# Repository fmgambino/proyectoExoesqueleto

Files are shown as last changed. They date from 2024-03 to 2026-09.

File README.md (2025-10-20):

# Proyecto Exoesqueleto Pediátrico con Monitoreo Biométrico

Logo de Electronicagambino

Este proyecto tiene como objetivo desarrollar un exoesqueleto pediátrico para niños con Atrofia Muscular Espinal (AME), incorporando monitoreo biométrico mediante IoT. El exoesqueleto permitirá a los niños con AME pararse y caminar con la ayuda de un andador, brindándoles una mayor autonomía y calidad de vida.

## Descripción del Firmware

El firmware se desarrollará utilizando PlatformIO con el framework Arduino mediante Visual Studio Code. Se utilizará el microcontrolador ESP32-WROOM-32U para controlar los motores paso a paso, gestionar la comunicación IoT y monitorear la actividad muscular mediante el sensor ECG EMG AD8832.

## Componentes Principales

- Microcontrolador ESP32-WROOM-32U
- Motores Paso a Paso Nema 17
- Sensores Mioeléctricos para detección de movimiento
- Sensor ECG EMG AD8832 para monitoreo de actividad muscular
- Conexión WiFi y Bluetooth Low Energy (BLE) para comunicación IoT

## Configuración del Entorno de Desarrollo

1. Instala PlatformIO en Visual Studio Code.
2. Clona este repositorio en tu computadora.
3. Abre el proyecto en Visual Studio Code.
4. Configura el archivo `platformio.ini` con la información del ESP32.
5. Compila y carga el firmware en el ESP32.

## Estructura del Proyecto

- **/src**: Contiene el código fuente del firmware.
- **/docs**: Documentación adicional del proyecto.
- **/hardware**: Esquemáticos y diseño de hardware.

## Diagramas y Esquemáticos

### Diagrama de Ingeniería Simplificado
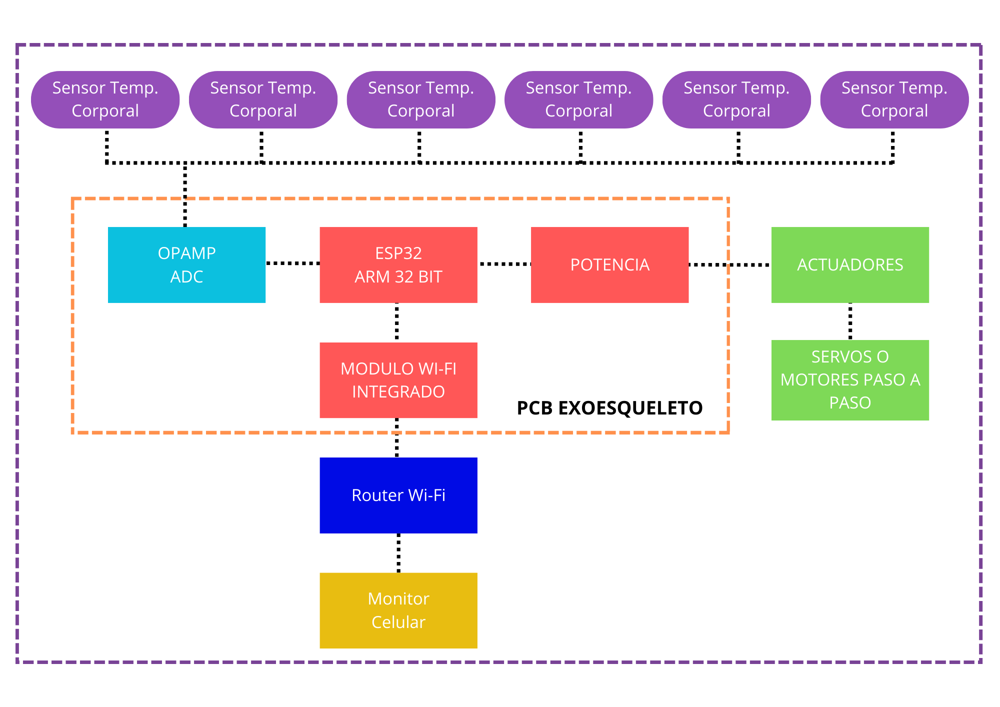
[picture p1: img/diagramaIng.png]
Diagrama de Ingeniería Simplificado


### Diagrama de Conectividad IoT mediante Broker EMQX
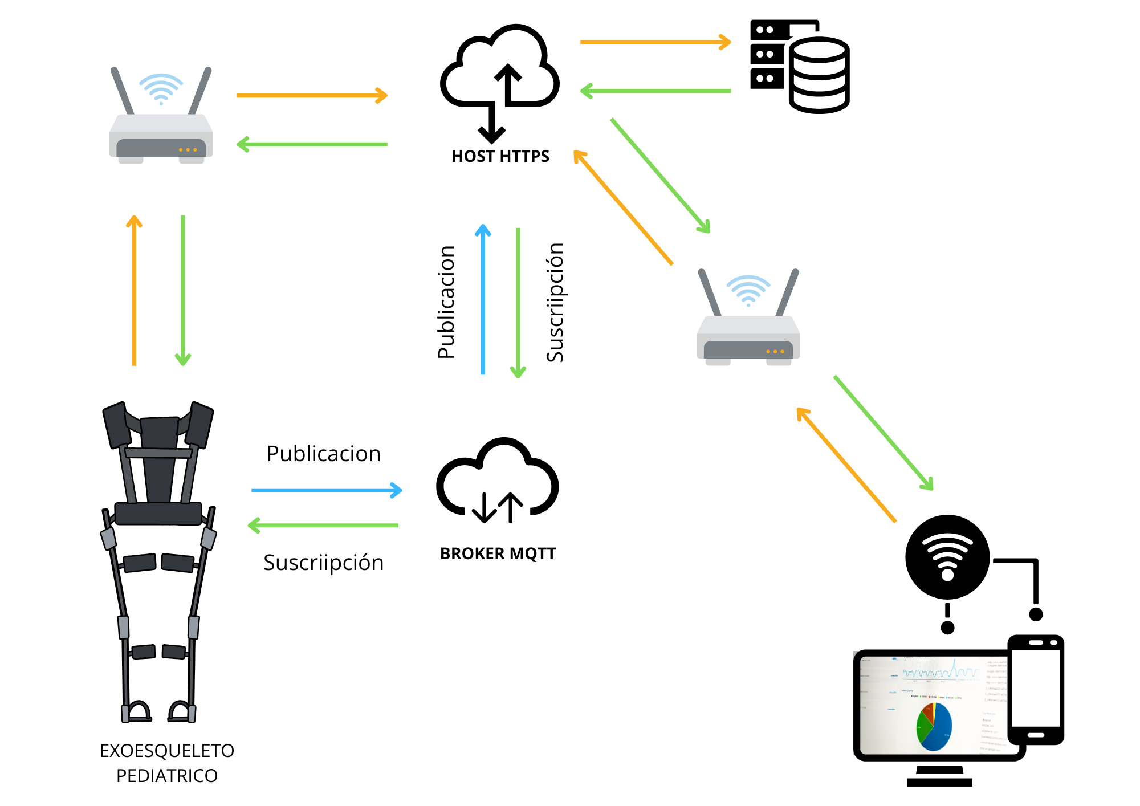
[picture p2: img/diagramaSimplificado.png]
Diagrama de Conectividad IoT


### Esquemático del Proyecto
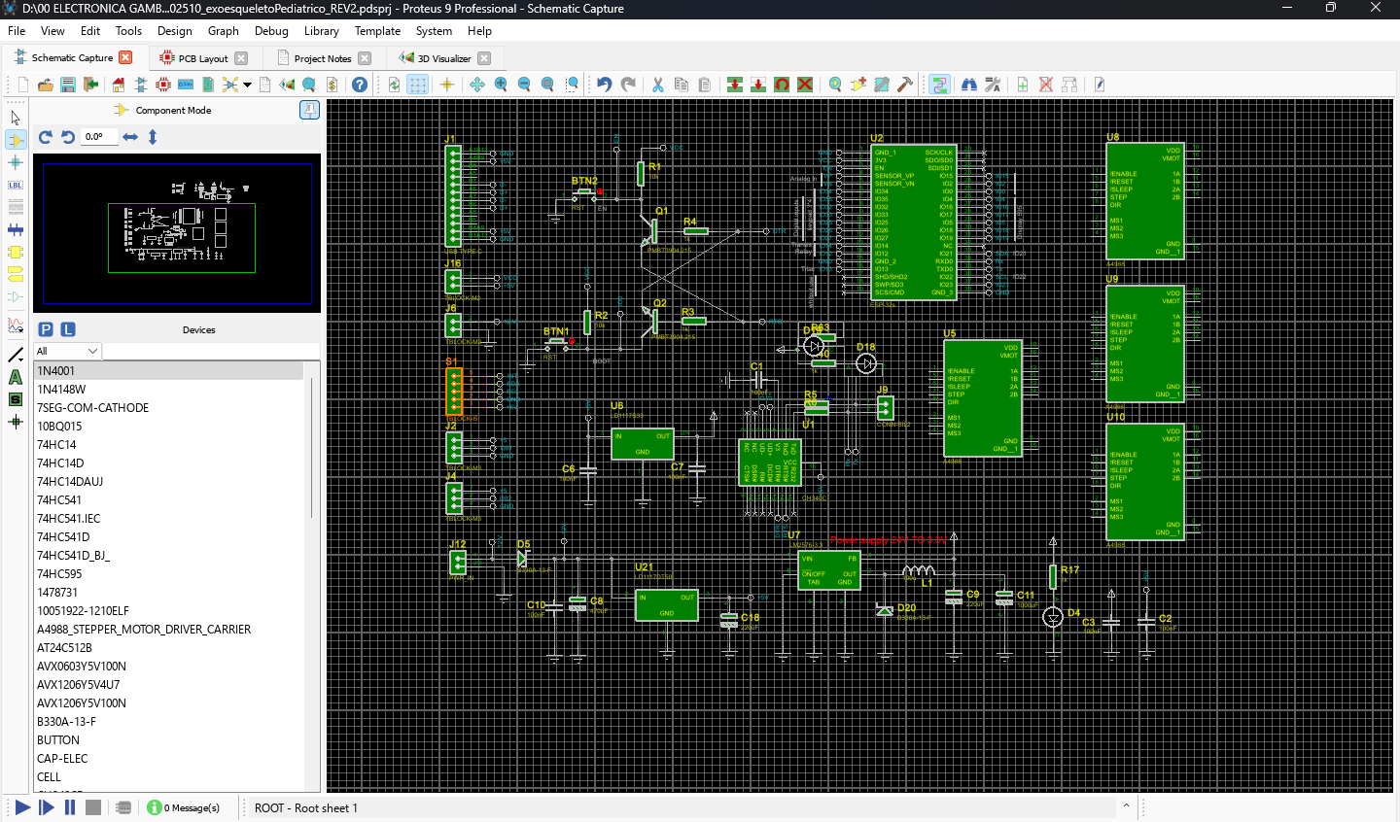
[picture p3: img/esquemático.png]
Esquemático


### Diseño  PCB LayOut´s del Proyecto
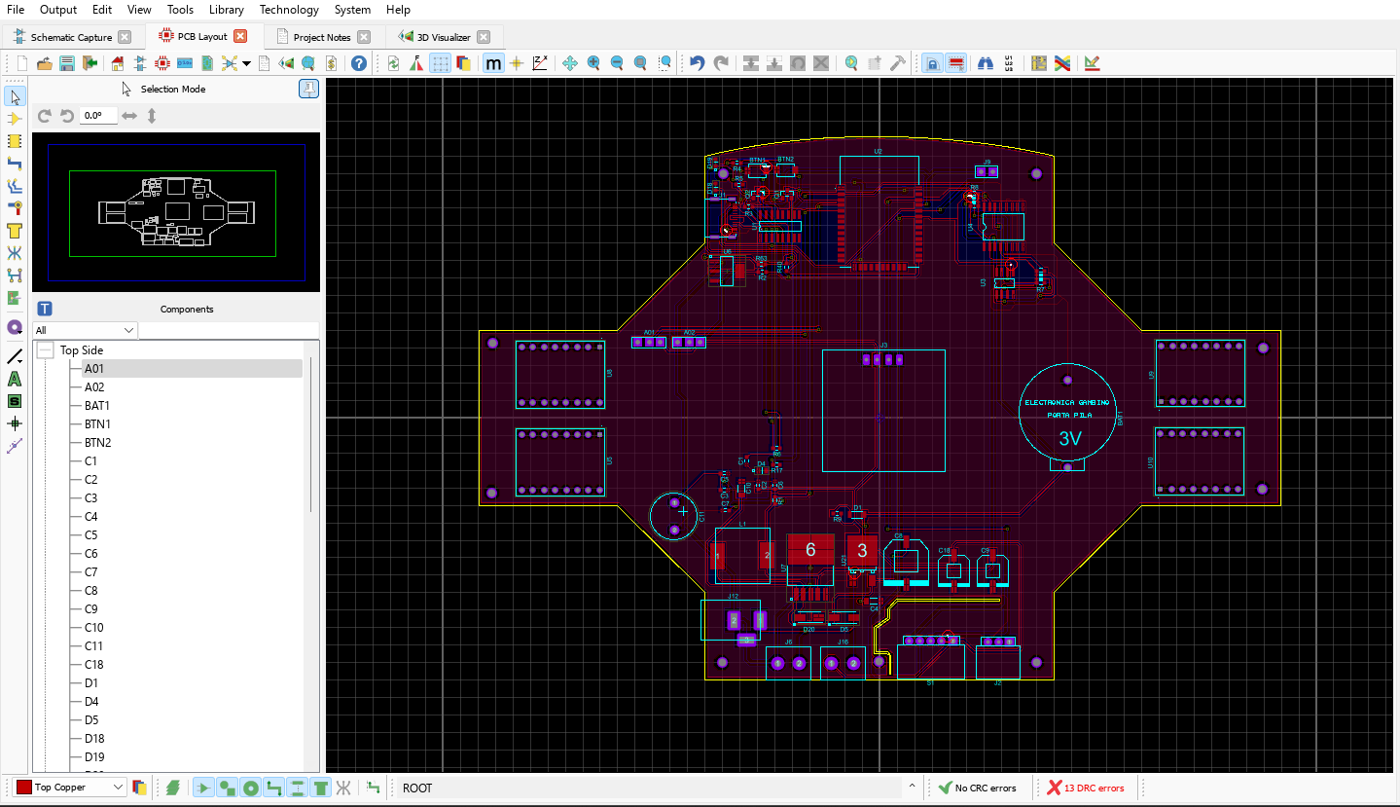
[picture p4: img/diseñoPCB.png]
PCB


### Modelado 3D PCB LayOut´s del Proyecto
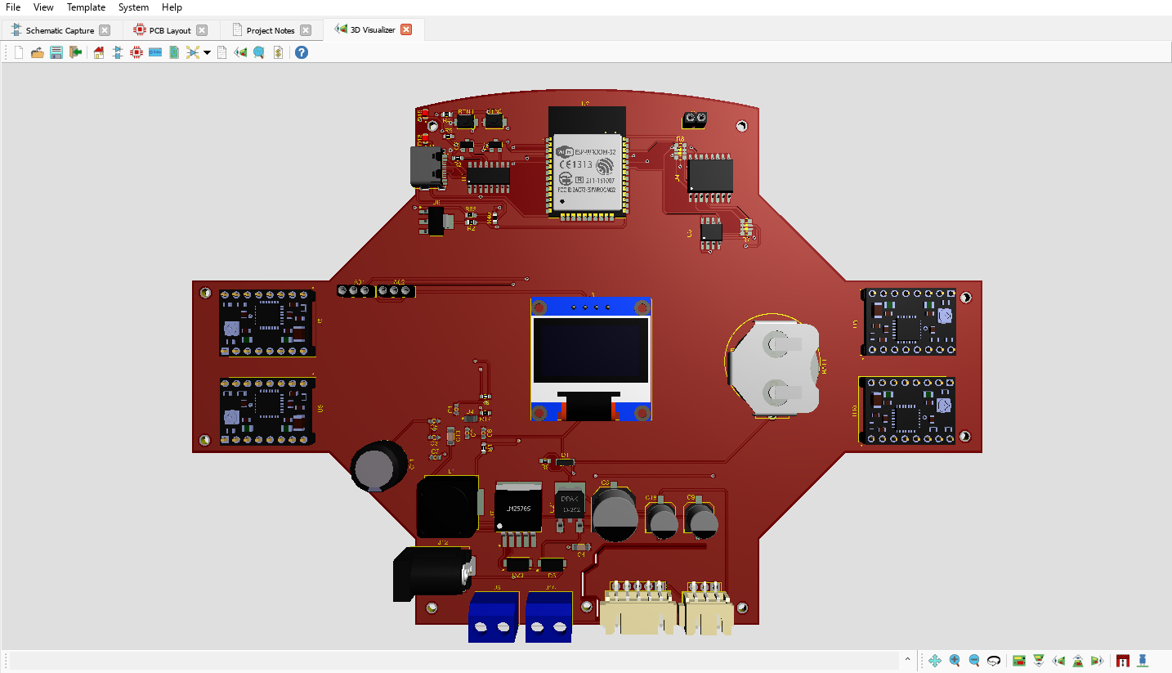
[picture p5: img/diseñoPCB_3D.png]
3D


## Uso del Firmware

El firmware controla los motores paso a paso en respuesta a las señales de los sensores mioeléctricos. Además, monitorea la actividad muscular utilizando el sensor ECG EMG AD8832. A continuación se describe cómo implementar y usar este sensor:

### Implementación del Sensor ECG EMG AD8832

1. Conecta el sensor ECG EMG AD8832 al pin analógico A0 del ESP32.
2. Proporciona la potencia adecuada al sensor según las especificaciones del fabricante.
3. Asegúrate de tener una buena conexión a tierra para reducir el ruido eléctrico.

### Detalles del Sensor

La medición de la actividad muscular se ha utilizado tradicionalmente en la investigación médica mediante la detección de la electromiografía (EMG). Sin embargo, con el advenimiento de microcontroladores más pequeños pero más potentes y circuitos integrados, los circuitos y sensores EMG se pueden utilizar en una variedad de aplicaciones de control de sistemas.

El sensor medirá la actividad eléctrica filtrada y rectificada de la salida muscular en un rango de 0 a Vs volts, donde la magnitud de la salida dependerá de la cantidad de actividad en el músculo seleccionado. Es fácil de usar con el controlador Arduino para detectar la actividad muscular.

### Forma de Uso del Sensor

El sensor ECG EMG AD8832 mide la actividad eléctrica de los músculos y proporciona una salida de voltaje proporcional a la actividad muscular. Puedes utilizar la siguiente función en tu código para medir esta actividad:

```cpp
#include <WiFi.h>
#include <BLEDevice.h>
#include <Stepper.h>

// Definición de pines para los motores paso a paso
#define MOTOR_1_STEP_PIN 2
#define MOTOR_1_DIR_PIN 3
#define MOTOR_2_STEP_PIN 4
#define MOTOR_2_DIR_PIN 5

// Definición de pines para el sensor muscular ECG EMG AD8832
#define EMG_SENSOR_PIN A0

// Definición de constantes para la configuración de los motores paso a paso
#define STEPS_PER_REVOLUTION 200
#define MOTOR_SPEED 200 // Velocidad en pasos por segundo

// Declaración de objetos Stepper para controlar los motores
Stepper stepperMotor1(STEPS_PER_REVOLUTION, MOTOR_1_STEP_PIN, MOTOR_1_DIR_PIN);
Stepper stepperMotor2(STEPS_PER_REVOLUTION, MOTOR_2_STEP_PIN, MOTOR_2_DIR_PIN);

// Variable para almacenar el estado del movimiento
bool isMoving = false;

// Función para inicializar la conexión WiFi
void setupWiFi() {
  // Coloca aquí tu código de inicialización de WiFi
}

// Función para inicializar la conexión BLE (Bluetooth Low Energy)
void setupBLE() {
  // Coloca aquí tu código de inicialización de BLE
}

// Función para inicializar el sensor muscular EMG
void setupEMGSensor() {
  pinMode(EMG_SENSOR_PIN, INPUT);
}

// Función para medir la actividad muscular con el sensor EMG
float measureMuscleActivity() {
  // Leer el valor del sensor EMG
  int emgValue = analogRead(EMG_SENSOR_PIN);

  // Convertir el valor a voltaje
  float voltage = emgValue * (3.3 / 4095.0); // 3.3V de referencia, 12 bits de resolución

  // Devolver el voltaje medido
  return voltage;
}

// Función para mover los motores paso a paso
void moveMotors() {
  // Coloca aquí tu código para controlar los motores según las señales de los sensores mioeléctricos
}

// Función de inicialización
void setup() {
  // Inicialización de los pines de dirección de los motores
  pinMode(MOTOR_1_DIR_PIN, OUTPUT);
  pinMode(MOTOR_2_DIR_PIN, OUTPUT);

  // Inicialización de la conexión WiFi
  setupWiFi();

  // Inicialización de la conexión BLE
  setupBLE();

  // Inicialización del sensor muscular EMG
  setupEMGSensor();
}

// Función principal de bucle
void loop() {
  // Coloca aquí tu código principal de control de bucle
  moveMotors();

  // Medir la actividad muscular con el sensor EMG
  float muscleActivity = measureMuscleActivity();

  // Imprimir el valor medido en el puerto serie
  Serial.print("Actividad Muscular: ");
  Serial.print(muscleActivity);
  Serial.println(" V");
  
  // Agrega un retraso para evitar lecturas demasiado rápidas
  delay(1000);
}
```
## Modelo 3D del Exoesqueleto Pediátrico

Aquí puedes ver el modelo 3D del exoesqueleto pediátrico desde diferentes ángulos:

### Frente
Modelo 3D Exoesqueleto Pediátrico Frontal

### Perfil
Modelo 3D Exoesqueleto Pediátrico Perfil

## Ubicación Recomendada de los Sensores EMG

Para maximizar la efectividad del exoesqueleto pediátrico, es crucial ubicar estratégicamente los sensores EMG en áreas específicas del cuerpo del niño o niña. Se recomienda colocar los sensores en los siguientes lugares:

1. **Músculos Cuádriceps y Femorales**: 💪 Estos músculos son fundamentales para el movimiento de las piernas y el equilibrio al estar de pie. Colocar los sensores en esta área permitirá detectar la intención de movimiento de las piernas y activar los motores del exoesqueleto en consecuencia.

2. **Músculos Tibiales Anteriores**: 🦵 Estos músculos están involucrados en la flexión dorsal del pie y son esenciales para mantener la estabilidad al caminar. Colocar sensores aquí ayudará a detectar los cambios en el equilibrio y ajustar el soporte proporcionado por el exoesqueleto.

3. **Músculos Glúteos**: 🍑 Los músculos glúteos son importantes para la estabilidad de la pelvis y el movimiento de las caderas. Colocar sensores en esta área puede ayudar a detectar la intención de movimiento de las caderas y mejorar la marcha del niño o niña.

4. **Zona Lumbar**: 🤸‍♀️ La zona lumbar es crucial para mantener la postura erguida y la estabilidad del tronco. Colocar sensores aquí permitirá monitorear la actividad muscular central y proporcionar soporte adecuado para la columna vertebral.

5. **Antebrazos y Bíceps**: 💪 Estos músculos son importantes para el equilibrio y la estabilidad al estar de pie. Colocar sensores en esta área puede ayudar a detectar los cambios en la postura de los brazos y ajustar el soporte proporcionado por el exoesqueleto.

## Consideraciones Adicionales para el Diseño del Hardware

Además de la ubicación de los sensores EMG, hay varias consideraciones adicionales que deben tenerse en cuenta en el diseño del hardware del exoesqueleto pediátrico:

- **Ergonomía**: 🪑 El diseño del exoesqueleto debe ser ergonómico y cómodo para el niño o niña, permitiendo un rango completo de movimiento y evitando puntos de presión incómodos.

- **Ajustabilidad**: 📏 Se debe permitir cierto grado de ajuste en el exoesqueleto para adaptarse al crecimiento del niño o niña y para permitir modificaciones según las necesidades individuales.

- **Seguridad**: ⚠️ El exoesqueleto debe ser seguro de usar, con mecanismos de seguridad para evitar lesiones y sensores de detección de fallos para garantizar un funcionamiento seguro.

- **Peso y Tamaño**: 📦 El exoesqueleto debe ser lo más liviano y compacto posible para facilitar el uso diario y minimizar la fatiga del usuario.

- **Facilidad de Uso**: 🎈 El exoesqueleto debe ser fácil de poner y quitar, con controles intuitivos y claros para el usuario y cuidador.

Considerar estas variables durante el diseño del hardware garantizará que el exoesqueleto pediátrico sea efectivo, seguro y cómodo para su uso continuo.

## 📚 Bibliografía y Referencias

- [Artículo científico sobre la ubicación de sensores EMG para exoesqueletos](https://www.ncbi.nlm.nih.gov/pmc/articles/PMC5378727/)
- [Investigación sobre diseño ergonómico de exoesqueletos](https://www.ncbi.nlm.nih.gov/pmc/articles/PMC5699460/)

# Tutorial: Control de Exoesqueleto con Sensores y PID 🤖📡

En este tutorial, aprenderás a utilizar un ESP32 junto con sensores de acelerómetro y giroscopio (MPU6050) para controlar un exoesqueleto, manteniéndolo en equilibrio mediante un controlador PID (Proporcional-Integral-Derivativo).

## Materiales necesarios 🛠️

- ESP32
- Sensor MPU6050 (acelerómetro y giroscopio)
- Motores Nema 17 (4 unidades)
- Driver A4988 (4 unidades)
- Placa de circuito impreso (PCB)
- Batería
- Cables de conexión
- Herramientas de soldadura

## Paso 1: Configuración del hardware 🚀

1. Conecta el ESP32 y el sensor MPU6050 según el esquema de conexión proporcionado en el archivo de configuración.

2. Conecta los motores Nema 17 al Driver A4988 y luego al ESP32, teniendo en cuenta la configuración de tu exoesqueleto.

## Paso 2: Configuración del entorno de desarrollo 💻

1. Instala el IDE de Arduino y el complemento PlatformIO para Visual Studio Code.

2. Crea un nuevo proyecto en PlatformIO y selecciona el framework Arduino y el ESP32 como placa de destino.

## Paso 3: Instalación de bibliotecas 📚

1. Instala las siguientes bibliotecas desde el administrador de bibliotecas de PlatformIO:
   - `Wire.h` (para la comunicación I2C)
   - `MPU6050.h` (para el sensor MPU6050)
   - `PID_v1.h` (para el controlador PID)

## Paso 4: Implementación del código 📝

Utiliza el siguiente código como base para tu proyecto. Asegúrate de personalizarlo según la configuración específica de tu exoesqueleto y ajustar los parámetros del controlador PID según sea necesario.

```cpp
#include <Arduino.h>
#include <Wire.h>
#include <MPU6050.h>
#include <PID_v1.h>

// Definir los pines de los motores
const int motorCintura1Pin1 = 2;
const int motorCintura1Pin2 = 3;
const int motorCintura2Pin1 = 4;
const int motorCintura2Pin2 = 5;
const int motorRodilla1Pin1 = 6;
const int motorRodilla1Pin2 = 7;
const int motorRodilla2Pin1 = 8;
const int motorRodilla2Pin2 = 9;

// Definir los pines de los sensores
MPU6050 mpu;

// Constantes para el equilibrio
const int anguloObjetivoCintura = 90; // Ángulo objetivo para la cintura
const int anguloObjetivoRodilla = 90; // Ángulo objetivo para las rodillas
const double Kp = 2.0; // Constante proporcional del PID
const double Ki = 5.0; // Constante integral del PID
const double Kd = 1.0; // Constante derivativa del PID

double inputCintura, outputCintura, setpointCintura;
double inputRodilla, outputRodilla, setpointRodilla;
PID pidCintura(&inputCintura, &outputCintura, &setpointCintura, Kp, Ki, Kd, DIRECT);
PID pidRodilla(&inputRodilla, &outputRodilla, &setpointRodilla, Kp, Ki, Kd, DIRECT);

void setup() {
  // Inicializar el puerto serie
  Serial.begin(9600);

  // Inicializar el sensor MPU6050
  Wire.begin();
  mpu.initialize();

  // Configurar los pines de los motores como salida
  pinMode(motorCintura1Pin1, OUTPUT);
  pinMode(motorCintura1Pin2, OUTPUT);
  pinMode(motorCintura2Pin1, OUTPUT);
  pinMode(motorCintura2Pin2, OUTPUT);
  pinMode(motorRodilla1Pin1, OUTPUT);
  pinMode(motorRodilla1Pin2, OUTPUT);
  pinMode(motorRodilla2Pin1, OUTPUT);
  pinMode(motorRodilla2Pin2, OUTPUT);
  
  // Configurar el PID
  pidCintura.SetMode(AUTOMATIC);
  pidRodilla.SetMode(AUTOMATIC);

  // Establecer los valores de setpoint
  setpointCintura = anguloObjetivoCintura;
  setpointRodilla = anguloObjetivoRodilla;
}

void loop() {
  // Leer los valores del sensor MPU6050
  int16_t ax, ay, az, gx, gy, gz;
  mpu.getMotion6(&ax, &ay, &az, &gx, &gy, &gz);
  
  // Calcular el ángulo de inclinación en la cintura y las rodillas
  double anguloCintura = atan2(-ay, -az) * 180.0 / M_PI;
  double anguloRodilla = atan2(-ax, -az) * 180.0 / M_PI;

  // Actualizar los valores de entrada del PID
  inputCintura = anguloCintura;
  inputRodilla = anguloRodilla;

  // Calcular la salida del PID
  pidCintura.Compute();
  pidRodilla.Compute();
  
  // Ajustar los motores según la salida del PID
  ajustarMotorCintura(outputCintura);
  ajustarMotorRodilla(outputRodilla);
}

void ajustarMotorCintura(double velocidad) {
  // Ajustar la velocidad y la dirección de los motores de la cintura
  // Implementar un algoritmo de control PID aquí
  // Este es un ejemplo simple donde se ajustan los motores de forma proporcional a la salida del PID
  if (velocidad > 0) {
    digitalWrite(motorCintura1Pin1, HIGH);
    digitalWrite(motorCintura1Pin2, LOW);
    digitalWrite(motorCintura2Pin1, HIGH);
    digitalWrite(motorCintura2Pin2, LOW);
  } else {
    digitalWrite(motorCintura1Pin1, LOW);
    digitalWrite(motorCintura1Pin2, HIGH);
    digitalWrite(motorCintura2Pin1, LOW);
    digitalWrite(motorCintura2Pin2, HIGH);
  }
}

void ajustarMotorRodilla(double velocidad) {
  // Ajustar la velocidad y la dirección de los motores de las rodillas
  // Implementar un algoritmo de control PID aquí
  // Este es un ejemplo simple donde se ajustan los motores de forma proporcional a la salida del PID
  if (velocidad > 0) {
    digitalWrite(motorRodilla1Pin1, HIGH);
    digitalWrite(motorRodilla1Pin2, LOW);
    digitalWrite(motorRodilla2Pin1, HIGH);
    digitalWrite(motorRodilla2Pin2, LOW);
  } else {
    digitalWrite(motorRodilla1Pin1, LOW);
    digitalWrite(motorRodilla1Pin2, HIGH);
    digitalWrite(motorRodilla2Pin1, LOW);
    digitalWrite(motorRodilla2Pin2, HIGH);
  }
}
```
## Paso 5: Compilación y carga del programa ⚙️

1. Compila el programa en PlatformIO y verifica que no haya errores.

2. Conecta el ESP32 a tu computadora y carga el programa compilado en el ESP32. Puedes hacerlo utilizando un cable USB.

## Paso 6: Pruebas y ajustes 🧪

1. Prueba el exoesqueleto en condiciones controladas, verificando su capacidad para mantener el equilibrio.

2. Ajusta los parámetros del controlador PID según sea necesario para mejorar el rendimiento del exoesqueleto.

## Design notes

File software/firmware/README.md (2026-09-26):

# BIOTRON EXO Pediátrico V7

Proyecto PlatformIO para ESP32 DevKit V1 + visor web 3D.

Correcciones V7:
- Error C++ de asignación `Joints` corregido con `assignJoints()`.
- Modelo 3D centrado y estado inicial sentado con rodillas a 90°.
- Señales DEMO ECG tipo AD8232 y EMG tipo burst muscular.
- Gráficas ECG/EMG con escalas y unidades: ECG 0-1200 mV, EMG 0-1000 mV, tiempo en segundos.
- Al deshabilitar ECG o EMG se oculta el bloque completo.
- Iconos SVG profesionales en variables biomédicas.
- OLED SH1106: logo, proyecto, autores y parámetros biomédicos.

## Uso
1. Abrir carpeta en VS Code + PlatformIO.
2. Borrar `.pio` si viene de versiones anteriores.
3. Compilar y subir firmware.
4. Subir filesystem: PlatformIO > Upload Filesystem Image.
5. Conectarse al AP `BIOTRON_EXO` / `12345678` y abrir la IP del ESP32.

IMPORTANTE: `ENABLE_MOTION` está en `false` por seguridad. Activarlo solo en banco, sin persona y con E-STOP.

## V8 - ECG simulado mejorado
- Señal ECG DEMO reescrita para parecerse al AD8232 mostrado en SignalScope: baseline cercano a 500, QRS angosto alto, P y T visibles, deriva basal y ruido fino.
- Escala gráfica ECG: eje X en segundos, eje Y 0-1000 mV relativos.
- El filtro ECG conserva el pico R para que la morfología no quede suavizada en exceso.

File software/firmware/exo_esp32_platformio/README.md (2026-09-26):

# Exoesqueleto Pediatrico ESP32 - PlatformIO

Proyecto base con ESP32 DevKit v1, Arduino Framework, 2 MPU6050, 4 motores NEMA17 mediante drivers STEP/DIR y telemetria WebSocket para modelo 3D en tiempo real.

## Comandos

```bash
pio run
pio run -t upload
pio run -t uploadfs
pio device monitor
```

Al iniciar, el ESP32 crea el AP `EXO_PEDIATRICO_ESP32` con clave `12345678`. Abrir `http://192.168.4.1`.

## Advertencia

Este codigo NO garantiza estabilidad ni seguridad humana. Para uso real hacen falta sensores adicionales, arnes, parada de emergencia cableada, topes fisicos, pruebas con carga dummy y revision biomecanica.

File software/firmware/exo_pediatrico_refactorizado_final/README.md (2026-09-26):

# Exoesqueleto pediátrico ESP32 + visor 3D

Proyecto PlatformIO para ESP32 DevKit v1 con Framework Arduino.

## Funciones
- Web local servida desde LittleFS.
- Visor 3D Three.js refactorizado con rotación X/Y/Z, OrbitControls y rueda de mouse configurable.
- Telemetría WebSocket en tiempo real.
- 2 MPU6050, 4 motores NEMA17, ECG, EMG, SpO2 MAX30102/MAX30105, temperatura corporal DS18B20, LM35 ambiente y temperatura CPU ESP32.

## Uso
1. Ajustar pines en `src/main.cpp`.
2. `pio run -t upload`
3. `pio run -t uploadfs`
4. Conectarse al WiFi `EXO-PEDIATRICO` clave `exo123456`.
5. Abrir `http://192.168.4.1`.

## Seguridad
Este firmware es base de laboratorio. No usar con un paciente sin arnés, paro de emergencia cableado, límites mecánicos, sensores de presión por pie, validación clínica y supervisión profesional.

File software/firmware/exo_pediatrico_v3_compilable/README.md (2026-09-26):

# EXO Pediátrico V3 - ESP32 DevKit V1

Corrección principal: `platformio.ini` actualizado para usar las librerías actuales de ESPAsyncWebServer:

```ini
esp32async/ESPAsyncWebServer
esp32async/AsyncTCP
```

El error anterior se debía a que `me-no-dev/ESP Async WebServer` / `me-no-dev/AsyncTCP` quedó obsoleto/movido en el registro de PlatformIO.

## Pasos recomendados después de reemplazar el proyecto

1. Cerrar VS Code.
2. Borrar la carpeta `.pio` del proyecto anterior.
3. Abrir esta carpeta nueva en VS Code.
4. Ejecutar `PlatformIO: Clean`.
5. Ejecutar `PlatformIO: Build`.
6. Para subir web a LittleFS: `PlatformIO: Upload Filesystem Image`.
7. Para subir firmware: `PlatformIO: Upload`.

## Modo web

La interfaz en `data/` conserva:
- selector DEMO / REAL,
- visor 3D,
- rotación X/Y/Z,
- scroll del mouse,
- telemetría biomédica y estado ESP32.

## Seguridad

`ENABLE_PHYSICAL_MOTION` está en `false` por defecto. No habilitar movimiento físico sin arnés, E-STOP físico, topes mecánicos, limit switches, sensores de presión en pies y validación en banco.

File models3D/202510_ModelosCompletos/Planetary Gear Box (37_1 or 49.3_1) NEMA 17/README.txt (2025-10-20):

Compound Planetary Gear Box (37:1 or 49.3:1) NEMA 17, No Hardware.  by Gear_Down_For_What on Thingiverse: https://www.thingiverse.com/thing:2054378

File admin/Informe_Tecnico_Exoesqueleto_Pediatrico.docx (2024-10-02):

# Informe Técnico: Evaluación de Servos para Exoesqueleto Pediátrico

## Introducción

Este informe técnico evalúa la factibilidad de usar cuatro servos RDS51150 para construir un exoesqueleto pediátrico para una niña de 150 cm de altura y 30 kg de peso. Se realizarán cálculos para determinar si estos servos pueden proporcionar el torque necesario para mover y sostener el peso de la niña.

## Datos del Servo y del Usuario

Datos del servo:
- Torque máximo: 150 kg·cm (14.715 N·m)
- Ángulo de control: 270°
- Voltaje: 12V

Datos del usuario:
- Altura de la niña: 150 cm
- Peso de la niña: 30 kg

## Consideraciones para el Exoesqueleto

1. Peso de la niña: 30 kg
2. Distribución del peso: Asumiremos que el exoesqueleto debe soportar el 50% del peso en cada pierna, es decir, 15 kg por pierna.
3. Distancia del punto de aplicación de la fuerza (longitud de la pierna): Aproximadamente la mitad de la altura de la niña, es decir, 75 cm.

## Cálculos

### Conversión del torque de los servos

El torque de los servos está dado en kg·cm, lo convertiremos a N·m para tener unidades consistentes.

1 kg·cm = 0.0981 N·m

Por lo tanto, 150 kg·cm = 150 * 0.0981 N·m = 14.715 N·m

### Fuerza necesaria por pierna

La fuerza necesaria para sostener 15 kg (parte del peso de la niña por pierna) es:

F = m * g = 15 kg * 9.81 m/s² = 147.15 N

### Momento de fuerza (Torque) necesario por pierna

El momento de fuerza (torque) necesario para levantar la pierna se calcula considerando la distancia desde el punto de rotación (asumiremos la cadera como punto de rotación):

τ = F * d = 147.15 N * 0.75 m = 110.3625 N·m

### Torque proporcionado por los servos

Cada pierna tendrá dos servos. Si se asume que el torque se distribuye uniformemente entre los dos servos por pierna, entonces el torque proporcionado por un servo será:

Torque proporcionado por servo = 14.715 N·m

## Evaluación de Factibilidad

Cada pierna necesita un torque de 110.3625 N·m, y cada pierna tendrá dos servos, por lo tanto, el torque total proporcionado por los dos servos será:

Torque total proporcionado por dos servos = 2 * 14.715 N·m = 29.43 N·m

Dado que 29.43 N·m es mucho menor que el torque necesario de 110.3625 N·m, los servos especificados no serán suficientes para mover y sostener el peso de la niña en un exoesqueleto.

## Conclusión

Los servos RDS51150 con un torque máximo de 150 kg·cm (14.715 N·m) no son adecuados para construir un exoesqueleto para una niña de 150 cm y 30 kg. Se requerirían servos con un torque significativamente mayor para soportar y mover el peso de la niña.

## Servos Adecuados

Para determinar qué servos serían adecuados, necesitamos calcular el torque mínimo necesario y buscar servos que cumplan o superen ese requisito. Hemos determinado que cada pierna requiere un torque de 110.3625 N·m para sostener la mitad del peso de la niña. Asumiremos que queremos usar dos servos por pierna, por lo que cada servo debe proporcionar la mitad de este torque.

Torque necesario por servo:
Torque necesario por servo = 55.18125 N·m

Conversión del torque a kg·cm:
Dado que 1 N·m = 10.1972 kg·cm,

Torque necesario por servo en kg·cm = 55.18125 N·m * 10.1972 kg·cm/N·m = 562.46 kg·cm

Por lo tanto, cada servo debe proporcionar al menos 562.46 kg·cm de torque.

Servos adecuados:
- Hitec HSR-5980SG: Torque máximo de aproximadamente 583 kg·cm (aproximadamente 57 N·m)
- Actuonix L16: Torque máximo varía según el modelo, pero algunos pueden alcanzar más de 562 kg·cm
- Dynamixel Pro+ H54-200-S500-R: Torque máximo de 44.7 N·m (es posible usar múltiples servos en configuraciones personalizadas para alcanzar el torque necesario)

En conclusión, se requieren servos con un torque mínimo de 562.46 kg·cm para garantizar la funcionalidad adecuada del exoesqueleto.

## Uso de Engranajes para Aumentar el Torque

Utilizar un mecanismo de engranajes puede multiplicar el torque proporcionado por los servos originales, haciéndolos potencialmente adecuados para el exoesqueleto.

Datos del servo original:
- Torque máximo: 150 kg·cm (14.715 N·m)

Torque necesario por pierna:
- Torque necesario: 110.3625 N·m
- Torque necesario por servo (si se usan dos por pierna): 55.18125 N·m

Ratio de engranaje necesario:
Ratio de engranaje = Torque necesario / Torque proporcionado
Ratio de engranaje = 55.18125 N·m / 14.715 N·m ≈ 3.75

Esto significa que necesitamos un sistema de engranajes con una relación de aproximadamente 3.75:1 para multiplicar el torque del servo original hasta alcanzar el torque requerido.

Consideraciones prácticas:
- Eficiencia: Los engranajes no son 100% eficientes. Debes considerar la pérdida de eficiencia, que puede ser alrededor del 90% o 0.9 para un buen sistema de engranajes.
- Espacio y peso: Los engranajes adicionales agregarán peso y ocuparán espacio, lo cual debe ser considerado en el diseño del exoesqueleto.

Ratio de engranaje ajustado con eficiencia:
Si asumimos una eficiencia del 90%:
Torque ajustado = Torque necesario / (Torque proporcionado * Eficiencia)
Ratio de engranaje ajustado = 55.18125 N·m / (14.715 N·m * 0.9) ≈ 4.17

En conclusión, se puede utilizar un sistema de engranajes con una relación de 4.17:1 para hacer que los servos originales sean adecuados para el exoesqueleto pediátrico.

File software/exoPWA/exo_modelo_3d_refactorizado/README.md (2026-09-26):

# Exoesqueleto Pediátrico 3D - Refactor

Abrir `index.html` con un servidor local, por ejemplo:

```bash
python -m http.server 8080
```

Luego entrar a `http://localhost:8080`.

Mejoras incluidas:
- OrbitControls sin bloqueo: giro completo, pan y zoom.
- Slider de rotación del modelo sobre eje Z.
- Diseño profesional tipo HUD.
- Animación GSAP estilo After Effects.
- WebSocket listo para ESP32: `ws://<host>:81/` con JSON `{lh,rh,lk,rk,rotZ}` en grados.

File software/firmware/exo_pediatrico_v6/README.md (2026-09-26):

# BIOTRON EXO Pediátrico V6

Proyecto PlatformIO para ESP32 DevKit v1 con visor 3D, telemetría biomédica, modo DEMO/REAL, OLED SH1106 y WebSocket.

## Correcciones V6
- Modelo 3D centrado y cámara corregida.
- Estado inicial sentado: rodillas a 90°.
- Logo BIOTRON en OLED como bitmap 128x64.
- Tarjetas biomédicas con iconos y unidades.
- Gráficas ECG y EMG en colores distintos, con ejes y unidades.
- Si se deshabilita ECG o EMG, la curva queda oculta.
- Demo simulada activa sin depender del ESP32.

## Uso
1. Abrir la carpeta en VS Code + PlatformIO.
2. Borrar `.pio` si existe.
3. Compilar: `PlatformIO: Build`.
4. Subir firmware: `PlatformIO: Upload`.
5. Subir web: `PlatformIO: Upload Filesystem Image`.
6. Conectarse al AP `BIOTRON_EXO`, contraseña `12345678`.

> Seguridad: `ENABLE_MOTION` está en `false`. Activarlo solo en banco de pruebas, sin persona.

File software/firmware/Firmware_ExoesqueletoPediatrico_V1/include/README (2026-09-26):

s” alimentada desde imágenes de reclamos.

## Cambiar imagen o video de fondo de la landing

### Imagen
Editá `styles.css`:

```css
.hero-section {
  --hero-image: linear-gradient(...), url('assets/hero-bg.svg');
}
```

Podés reemplazar `assets/hero-bg.svg` por `assets/hero-bg.jpg` o cualquier imagen propia.

### Video
En `index.html`, buscá:

```html
<!-- <video class="hero-video" autoplay muted loop playsinline src="assets/hero-bg.mp4"></video> -->
```

Quitá los comentarios y subí tu video como:

```text
assets/hero-bg.mp4
```

## Base de datos

No necesitás una columna nueva para URL de imagen: se guarda en `reports.image_urls` junto con las imágenes subidas. Ejecutá igualmente `database/database.sql` si venís de una versión anterior para asegurar columnas, políticas y Storage.

## v8 - Slider, landing y Cafecito

- El bloque **“Así se ven las calles”** ahora usa un slider interactivo con imágenes o video de los reclamos.
- Desde el **Panel Administrador > Slider de evidencia** podés cambiar efecto: `Slide`, `Fade` o `Zoom`, tiempo en milisegundos y autoplay.
- Se agregó sección **“Quién impulsa esta iniciativa”**.
- Se agregó botón **Cafecito** en header y footer.
- El popup del marcador muestra imagen principal 500x500px, antigüedad, fecha de reporte y estado con borde/color.

Para persistir la configuración del slider en Sup

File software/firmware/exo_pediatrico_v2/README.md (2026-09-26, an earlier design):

# EXO Pediátrico ESP32 + Visor 3D V2

Proyecto PlatformIO para ESP32 DevKit V1 con visor 3D, modo DEMO con datos simulados y modo REAL por WebSocket.

## Uso
1. Abrir con PlatformIO.
2. Compilar y subir firmware: `pio run -t upload`.
3. Subir web al LittleFS: `pio run -t uploadfs`.
4. Conectarse al WiFi `EXO-PEDIATRICO`, clave `exo123456`.
5. Abrir `http://192.168.4.1/`.

## Modo visualizador
- DEMO: no requiere ESP32; genera telemetría y movimientos simulados.
- REAL: conecta al WebSocket del ESP32 y muestra sensores/motores reales.

## Controles 3D
- Arrastrar mouse: orbitar.
- Rueda: zoom o rotación según selector.
- Shift + rueda: rotación Y.
- Alt + rueda: rotación X.
- Sliders X/Y/Z: rotación absoluta del modelo.

## Seguridad
Este firmware es una base de banco y visualización. No habilita movimiento físico por defecto. Para pruebas con persona se requieren sensores redundantes, topes mecánicos, E-STOP cableado, arnés y validación clínica/ingenieril.

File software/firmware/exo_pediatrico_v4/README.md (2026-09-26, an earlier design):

# EXO Pediátrico V4 - ESP32 DevKit V1 + visor 3D + ECG/EMG

Proyecto PlatformIO / Arduino para ESP32 DevKit V1.

## Cambios V4
- Estado inicial visual y lógico: **sentado a 90°**.
- Botón **Pararse + caminatas**: levanta desde sentado y ejecuta secuencia adelante, atrás, derecha e izquierda.
- Modelo 3D más parecido al prototipo: parte superior tipo carrito/trolley, placa negra, rieles laterales, rueditas, perfiles negros, carcazas grises, NEMA17 y pies pediátricos.
- Rotación X/Y/Z por sliders y rueda del mouse.
- Selector **DEMO / REAL**.
- Popup con gráficas ECG y EMG usando Chart.js CDN, con filtros independientes de visualización.
- Librerías PlatformIO corregidas: `esp32async/ESPAsyncWebServer` y `esp32async/AsyncTCP`.

## Uso
1. Abrir la carpeta en VS Code + PlatformIO.
2. Borrar `.pio` si viene de un proyecto anterior.
3. Compilar: `PlatformIO: Build`.
4. Subir firmware: `PlatformIO: Upload`.
5. Subir web: `PlatformIO: Upload Filesystem Image`.
6. Abrir la IP que muestra el monitor serial. Si no conecta WiFi, crea AP: `EXO-PEDIATRICO` clave `12345678`.

## Seguridad
`ENABLE_MOTION` está en `false` por defecto. Cambiar a `true` solo en banco de pruebas, sin persona, con E-STOP físico, arnés, topes mecánicos, sensores de presión en pies, encoders absolutos y supervisión.

Con 2 MPU6050 no se puede garantizar que no caiga. Para uso real se recomiendan: sensores FSR/celdas de carga por pie, encoders absolutos en articulaciones, finales de carrera, IMU adicional en torso, botón E-STOP cableado, medición de corriente de motores y arnés.

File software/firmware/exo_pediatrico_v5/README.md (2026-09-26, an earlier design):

# BIOTRON EXO Pediátrico V5

Correcciones incluidas:
- Visor 3D visible y más parecido al prototipo: trolley superior, perfiles negros, carcasas grises, NEMA17, cableado y pies pediátricos.
- Modo DEMO / REAL. DEMO muestra datos simulados aunque no haya ESP32 conectado.
- Secuencia inicial: sentado 90° → pararse → caminata adelante, atrás, derecha e izquierda.
- Popup con gráficas ECG y EMG usando Chart.js, con señal filtrada por separado.
- Firmware PlatformIO ESP32 DevKit v1 corregido sin `StaticJsonDocument`.
- OLED SH1106: logo/texto BIOTRON, pantalla de proyecto, autores y parámetros biomédicos.

## Uso
1. Abrir el proyecto en VS Code + PlatformIO.
2. Ejecutar `Build`.
3. Ejecutar `Upload Filesystem Image`.
4. Ejecutar `Upload`.
5. Conectarse al AP `BIOTRON_EXO`, password `12345678`, abrir `http://192.168.4.1/`.

## Seguridad
`ENABLE_MOTION` está en `false`. Cambiar a `true` solo en banco de pruebas, sin persona, con paro de emergencia físico, finales de carrera, arnés y supervisión.

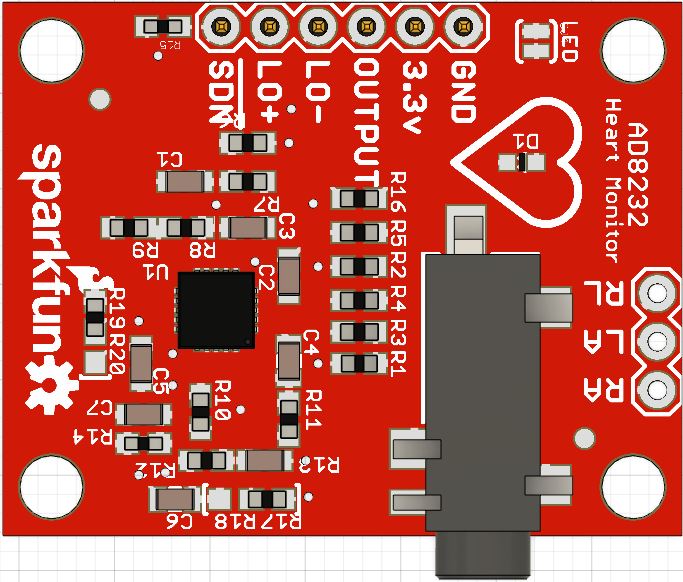
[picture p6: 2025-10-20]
hardware/mcad/ad8232-2.snapshot.2/AD83232.JPG

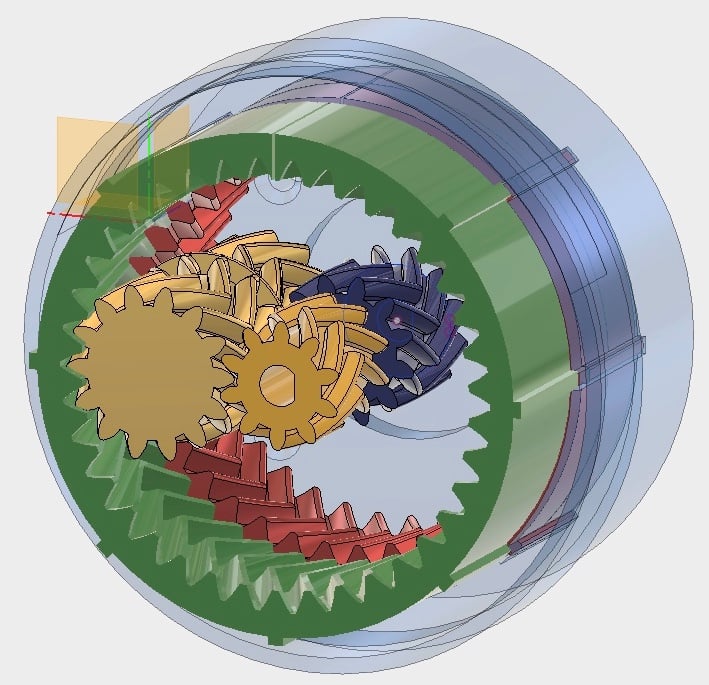
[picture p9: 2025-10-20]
models3D/202510_ModelosCompletos/Planetary Gear Box (37_1 or 49.3_1) NEMA 17/images/fullsizeoutput_700.jpeg

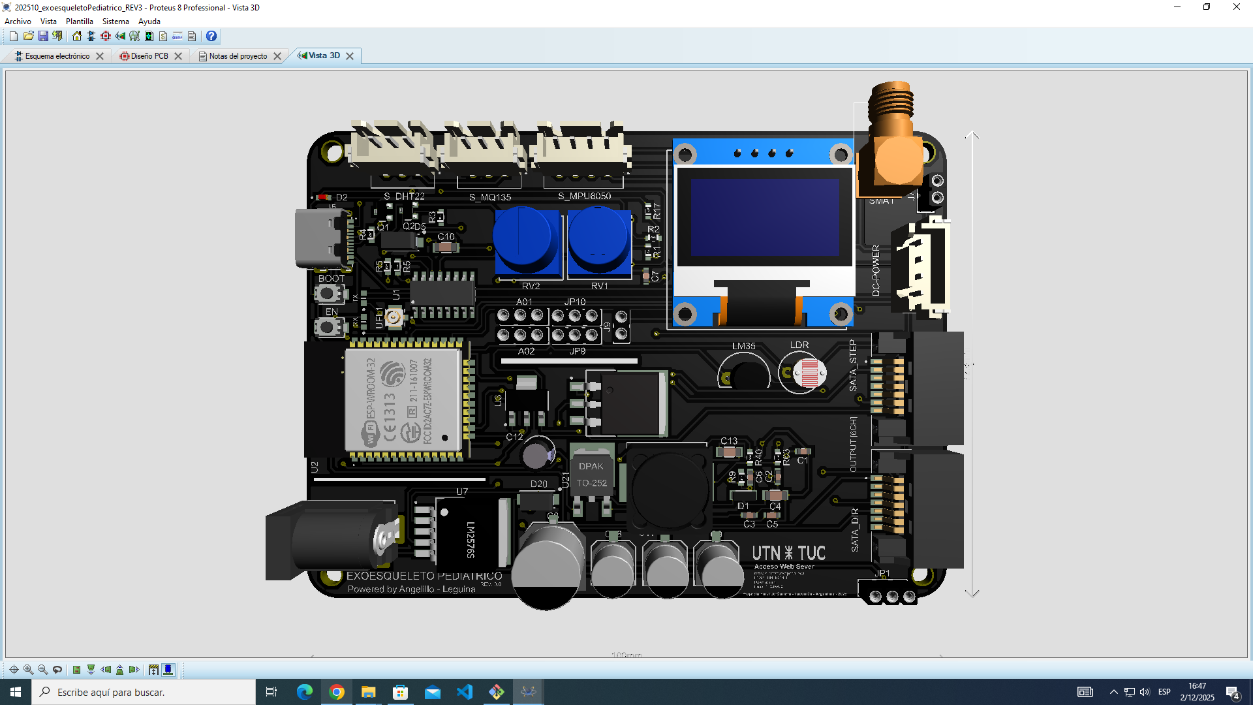
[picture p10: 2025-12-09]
img/pcbExo__control_frontal.png

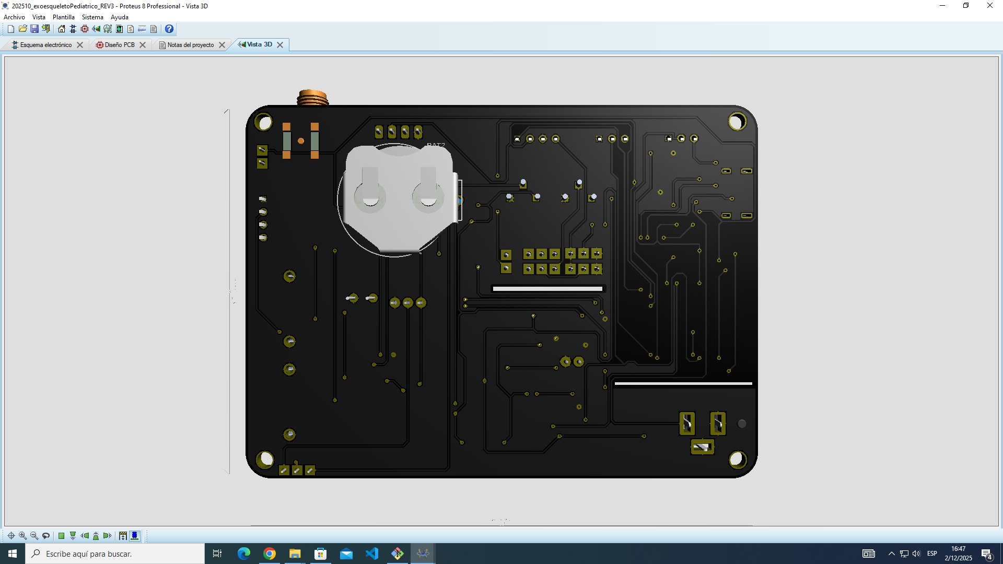
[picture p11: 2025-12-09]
img/pcbExo__control_reverso.png

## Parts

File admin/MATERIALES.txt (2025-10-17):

*MATERIALES* 

1 Rollo c/carretel
30 Tuercas m2
30 Tornillos Allen M5x10mm
3 Motores Nema 17
4 Drive A4988
2 Baterías CNHL Black Serie 6s 1100mAh 22.2V 
ó Fuente Switching Metálica 24v 10a

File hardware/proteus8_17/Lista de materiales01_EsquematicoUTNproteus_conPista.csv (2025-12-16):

Categoría | Referencias | Valor | Código almacén | Coste unitario
Condensadores | C1 | 47uF | C264234 | $0.03
Condensadores | C2 | 100nF | C77055 | $0.01
Condensadores | C3 | 470uF | C263985 | $0.11
Condensadores | C4 | 220uF | C294521 | $0.04
Condensadores | C5 | 100nF | C77055 | $0.01
Condensadores | C6 | 100nF | C77055 | $0.01
Condensadores | C7 | 100nF | C77055 | $0.01
Condensadores | C8 | 100nF | C77055 | $0.01
Condensadores | C9 | 100nF | C77055 | $0.01
Condensadores | C10 | 100nF | C77055 | $0.01
Condensadores | C11 | 100nF | C77055 | $0.01
Condensadores | C12 | 100nF | C77055 | $0.01
Condensadores | C13 | 220uF | C294521 | $0.04
Condensadores | C19 | 100nF | C77055 | $0.01
Condensadores | C22 | 100nF | C77055 | $0.01
Condensadores | C23 | 100nF | C77055 | $0.01
Condensadores | C24 | 100nF | C77055 | $0.01
Condensadores | C25 | 100nF | C77055 | $0.01
Condensadores | C34 | 10uF | C513774 | $0.06
Condensadores | C35 | 100nF | C77055 | $0.01
Resistencias | R1 | 680 | C103775 | $0.00
Resistencias | R2 | 680 | C103775 | $0.00
Resistencias | R3 | 680 | C103775 | $0.00
Resistencias | R4 | 680 | C103775 | $0.00
Resistencias | R5 | 10k | C73809 | $0.00
Resistencias | R6 | 10k | C73809 | $0.00
Resistencias | R7 | 10k | C73809 | $0.00
Resistencias | R8 | 10k | C73809 | $0.00
Resistencias | R9 | 10k | C73809 | $0.00
Resistencias | R10 | 10k | C73809 | $0.00
Resistencias | R11 | 10k | C73809 | $0.00
Resistencias | R12 | 10k | C73809 | $0.00
Resistencias | R13 | 1k | C328340 | $0.00
Resistencias | R14 | 4.7K
Resistencias | R15 | 4.7K
Resistencias | R16 | 4.7K
Resistencias | R17 | 20k | C305317 | $0.00
Resistencias | R18 | 20k | C305317 | $0.00
Resistencias | R19 | 20k | C305317 | $0.00
Resistencias | R20 | 20k | C305317 | $0.00
Resistencias | R21 | 680 | C103775 | $0.00
Resistencias | R22 | 680 | C103775 | $0.00
Resistencias | R23 | 680 | C103775 | $0.00
Resistencias | R24 | 680 | C103775 | $0.00
Resistencias | R25 | 4.7K
Resistencias | R26 | 4.7K
Resistencias | R27 | 4.7K
Resistencias | R28 | 10k | C73809 | $0.00
Resistencias | R29 | 10k | C73809 | $0.00
Resistencias | R30 | 1k | C328340 | $0.00
Resistencias | R31 | 1k | C328340 | $0.00
Resistencias | R33 | 1k | C328340 | $0.00
Resistencias | R34 | 1k | C328340 | $0.00
Resistencias | R35 | 4.7K
Resistencias | R36 | 4.7K
Resistencias | R51 | 10k | C17414 | $0.00
Resistencias | R52 | 1k | C25623 | $0.00
Resistencias | R53 | 220 | C103414 | $0.00
Resistencias | R54 | 10k | C17414 | $0.00
Resistencias | R55 | 10k | C17414 | $0.00
Resistencias | R56 | 1k | C25623 | $0.00
Resistencias | R57 | 220 | C103414 | $0.00
Resistencias | R58 | 10k | C17414 | $0.00
Resistencias | R59 | 10k | C17414 | $0.00
Resistencias | R60 | 1k | C25623 | $0.00
Resistencias | R61 | 220 | C103414 | $0.00
Resistencias | R62 | 10k | C17414 | $0.00
Resistencias | R63 | 10k | C17414 | $0.00
Resistencias | R64 | 1k | C25623 | $0.00
Resistencias | R65 | 220 | C103414 | $0.00
Resistencias | R66 | 10k | C17414 | $0.00
Resistencias | R71 | 10k | C73809 | $0.00
Resistencias | R72 | 10k | C73809 | $0.00
Resistencias | R73 | 10k | C73809 | $0.00
Resistencias | R74 | 10k | C73809 | $0.00
Resistencias | R84 | 470 | C328361 | $0.00
Integrados | U1 | 74HC14 | C6821 | $0.12
Integrados | U2 | PC817XI1J
Integrados | U4 | PC817XI1J
Integrados | U5 | PC817XI1J
Integrados | U6 | PC817XI1J
Integrados | U7 | PC817XI1J
Integrados | U8 | DS3231SN
Integrados | U9 | TS78M05CP
Integrados | U10 | ESP-32s | C473012 | $3.19
Integrados | U11 | LM2576-3,3 | C194472 | $0.41
Integrados | U12 | LD1117S33 | C369933 | $0.07
Integrados | U13 | CH340C | C84681 | $0.39
Integrados | U14 | PC817XI1J
Integrados | U15 | PC817XI1J
Integrados | U16 | PC817XI1J
Integrados | U17 | ULN7812 TO263
Integrados | U18 | AT24C512B | C81193 | $0.18
Transistores | Q1 | PMBT3904,215 | C8667 | $0.01
Transistores | Q2 | PMBT3904,215 | C8667 | $0.01
Transistores | Q7 | FQD11P06TM | C719783 | $0.40
Transistores | Q8 | FQD11P06TM | C719783 | $0.40
Transistores | Q9 | FQD11P06TM | C719783 | $0.40
Transistores | Q10 | FQD11P06TM | C719783 | $0.40
Diodos | D00 | LED smd 0603 | C131269 | $0.03
Diodos | D01 | LED smd 0603 | C131269 | $0.03
Diodos | D02 | LED smd 0603 | C131269 | $0.03
Diodos | D03 | LED smd 0603 | C131269 | $0.03
Diodos | D9 | LED smd 0603 | C131269 | $0.03
Diodos | D10 | LED smd 0603 | C131269 | $0.03
Diodos | D11 | LED smd 0603 | C131269 | $0.03
Diodos | D12 | LED smd 0603 | C131269 | $0.03
Diodos | D28 | SS14-TP | C78082 | $0.05
Diodos | D29 | B330A-13-F | C110485 | $0.11
Diodos | D66 | 1N4148W | C511885 | $0.02
Miscelánea | BAT1 | 3V | C70376 | $0.06
Miscelánea | BTN1 | RST | C561519 | $0.06
Miscelánea | BTN2 | RST | C561519 | $0.06
Miscelánea | F1 | 1A | C3130 | $0.02
Miscelánea | FUENTE | TBLOCK-M2BLK |  | $0.40
Miscelánea | J1 | USB TYPE C | C309349 | $0.50
Miscelánea | J2 | HLK-10M12
Miscelánea | J3 | TBLOCK-M4
Miscelánea | J4 | TBLOCK-M4
Miscelánea | J6 | TBLOCK-M4
Miscelánea | J7 | TBLOCK-M2 |  | $0.40
Miscelánea | J8 | TBLOCK-M3
Miscelánea | L1 | 100u | C408533 | $0.55
Miscelánea | LCD | CONN-H4
Miscelánea | PW | LED-RED | C375458 | $0.02
Miscelánea | SPI | CONN-SIL6
Miscelánea | WI FI

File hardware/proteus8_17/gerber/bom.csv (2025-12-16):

Categoría | Referencias | Valor | Código almacén | Coste unitario
Condensadores | C1 | 100nF | C92490 | $0.00
Condensadores | C2 | 100nF | C92490 | $0.00
Condensadores | C3 | 100nF | C92490 | $0.00
Condensadores | C4 | 10uF | C513774 | $0.06
Condensadores | C5 | 100nF | C92490 | $0.00
Condensadores | C6 | 100nF | C92490 | $0.00
Condensadores | C7 | 100nF | C92490 | $0.00
Condensadores | C8 | 470uF | C263985 | $0.11
Condensadores | C9 | 220uF | C294521 | $0.04
Condensadores | C10 | 100nF | C309030 | $0.01
Condensadores | C11 | 1000uF | C503217 | $0.07
Condensadores | C12 | 220uF
Condensadores | C13 | 100nF | C309030 | $0.01
Condensadores | C18 | 220uF | C294521 | $0.04
Resistencias | R1 | 10k | C73809 | $0.00
Resistencias | R2 | 10k | C73809 | $0.00
Resistencias | R3 | 1k | C328340 | $0.00
Resistencias | R4 | 1k | C328340 | $0.00
Resistencias | R5 | 1k | C328340 | $0.00
Resistencias | R6 | 1k | C328340 | $0.00
Resistencias | R9 | 470 | C328361 | $0.00
Resistencias | R17 | 1k | C328340 | $0.00
Resistencias | R40 | 1k | C328340 | $0.00
Resistencias | R63 | 1k | C328340 | $0.00
Integrados | U1 | CH340C | C84681 | $0.39
Integrados | U2 | ESP-32s | C473012 | $3.19
Integrados | U3 | LM7812S
Integrados | U6 | LD1117S33 | C917183 | $0.13
Integrados | U7 | LM2576-3,3 | C347412 | $0.72
Integrados | U21 | LD1117DT50
Transistores | Q1 | PMBT3904,215 | C8667 | $0.01
Transistores | Q2 | PMBT3904,215 | C8667 | $0.01
Diodos | D1 | 1N4148W | C511885 | $0.02
Diodos | D2 | SMLD12U1WT86
Diodos | D5 | B330A-13-F | C110485 | $0.11
Diodos | D18 | LED-GREEN | C131269 | $0.03
Diodos | D19 | LED-GREEN | C131269 | $0.03
Diodos | D20 | B330A-13-F | C110485 | $0.11
Miscelánea | A01 | CONN-SIL3
Miscelánea | A02 | CONN-SIL3
Miscelánea | BAT2 | 3V | C70376 | $0.06
Miscelánea | BOOT | RST | C561523 | $0.06
Miscelánea | DC-POWER | B4BXHA
Miscelánea | EN | RST | C561523 | $0.06
Miscelánea | J1 | PWR_IN | Jack power
Miscelánea | J3 | OLED 128X64 | C30621 | $5.90
Miscelánea | J5 | USB TYPE C | C309349 | $0.50
Miscelánea | J7 | CONN-SIL2 | C492401 | $0.01
Miscelánea | J9 | CONN-SIL2 | C492401 | $0.01
Miscelánea | JP1 | JUMPER2
Miscelánea | JP9 | JUMPER2
Miscelánea | JP10 | JUMPER2
Miscelánea | L1 | 100u | C408533 | $0.55
Miscelánea | LDR | TORCH_LDR
Miscelánea | LM35 | LM35
Miscelánea | RV1 | 1k | C330455 | $0.43
Miscelánea | RV2 | 1k | C330455 | $0.43
Miscelánea | SATA_DIR | SATA_DATA
Miscelánea | SATA_STEP | SATA_DATA
Miscelánea | SMA1 | SMACONN
Miscelánea | S_ECG | CONNX3_MINI
Miscelánea | S_EMG | CONNX3_MINI
Miscelánea | S_MPU6050 | B4BXHA
Miscelánea | S_SPO2 | B4BXHA
Miscelánea | UFL1 | PIN UFL SMD

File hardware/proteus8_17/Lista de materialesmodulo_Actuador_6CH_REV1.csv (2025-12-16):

Categoría | Referencias | Valor | Código almacén | Coste unitario
Integrados | U1 | A4988
Integrados | U2 | A4988
Integrados | U3 | A4988
Integrados | U4 | A4988
Integrados | U5 | A4988
Integrados | U6 | A4988
Miscelánea | DC-POWER | B4BXHA
Miscelánea | J1 | TBLOCK-I4
Miscelánea | J2 | TBLOCK-I4
Miscelánea | J3 | TBLOCK-I4
Miscelánea | J4 | TBLOCK-I4
Miscelánea | J5 | TBLOCK-I4
Miscelánea | J6 | TBLOCK-I4
Miscelánea | SATA_DIR | SATA_DATA
Miscelánea | SATA_STEP | SATA_DATA

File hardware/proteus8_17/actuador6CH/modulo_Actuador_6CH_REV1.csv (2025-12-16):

Part ID | Value | Package | Stock Code | Layer | Rotation | X | Y
U1 | A4988 | A4988_MODULE_STEPPER_MOTOR_DRIVER_CARRIE |  | TOP | 0 | 775.984 | -1116.14
U2 | A4988 | A4988_MODULE_STEPPER_MOTOR_DRIVER_CARRIE |  | TOP | 0 | 775.984 | -1848.43
U3 | A4988 | A4988_MODULE_STEPPER_MOTOR_DRIVER_CARRIE |  | TOP | 0 | 1630.31 | -1116.14
U4 | A4988 | A4988_MODULE_STEPPER_MOTOR_DRIVER_CARRIE |  | TOP | 0 | 1618.5 | -1852.36
SATA_DIR | SATA_DATA | SATA_DATA |  | TOP | 90 | 1183.86 | -425.098
SATA_STEP | SATA_DATA | SATA_DATA |  | TOP | 90 | 2114.57 | -422.736
J1 | TBLOCK-I4 | CONN-SIL4 |  | TOP | 0 | 901.969 | -2299.21
J2 | TBLOCK-I4 | CONN-SIL4 |  | TOP | 0 | 1542.91 | -2303.15
J3 | TBLOCK-I4 | CONN-SIL4 |  | TOP | 0 | 2172.83 | -2307.09
J4 | TBLOCK-I4 | CONN-SIL4 |  | TOP | 0 | 906.693 | -2586.61
DC-POWER | B4BXHA | CONN-SIL4 |  | TOP | -90 | 236.22 | -1368.9
J5 | TBLOCK-I4 | CONN-SIL4 |  | TOP | 0 | 1543.7 | -2586.61
J6 | TBLOCK-I4 | CONN-SIL4 |  | TOP | 0 | 2173.62 | -2582.68
U5 | A4988 | A4988_MODULE_STEPPER_MOTOR_DRIVER_CARRIE |  | TOP | 0 | 2500.39 | -1116.14
U6 | A4988 | A4988_MODULE_STEPPER_MOTOR_DRIVER_CARRIE |  | TOP | 0 | 2500.39 | -1852.36

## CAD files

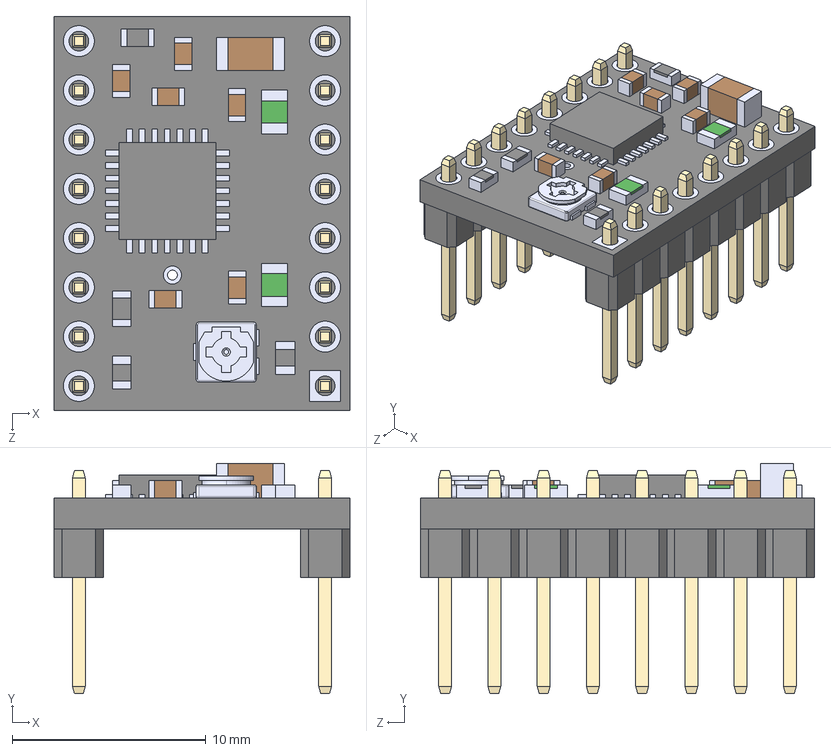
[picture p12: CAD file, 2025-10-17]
hardware/footprints/A4988_STEPPER_MOTOR_DRIVER_CARRIER/A4988_STEPPER_MOTOR_DRIVER_CARRIER.step
15.2 x 11.9 x 20.3 mm

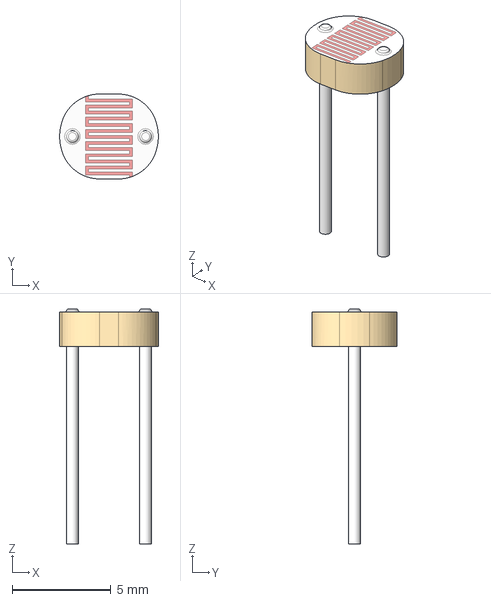
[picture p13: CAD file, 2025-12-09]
hardware/mcad/LDR v1.step
4.99 x 4.30 x 11.9 mm

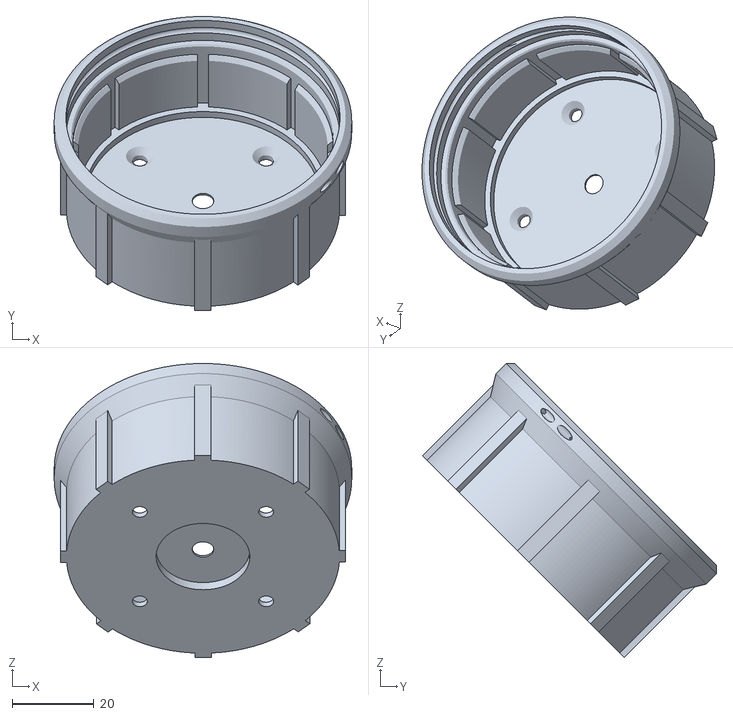
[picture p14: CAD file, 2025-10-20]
models3D/202510_ModelosCompletos/Planetary Gear Box (37_1 or 49.3_1) NEMA 17/files/Nema17_Mount_Update3_.stl
73.0 x 72.1 x 72.1

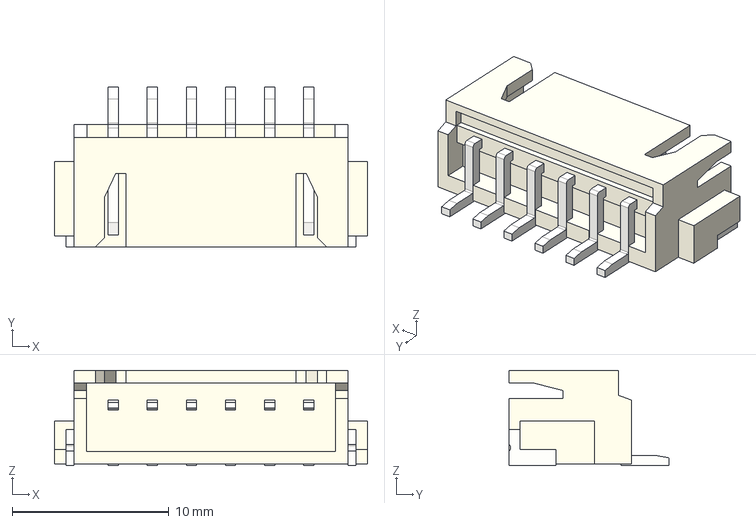
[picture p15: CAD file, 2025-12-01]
hardware/mcad/JST-XH6-SMD.step
20.0 x 10.2 x 6.10 mm

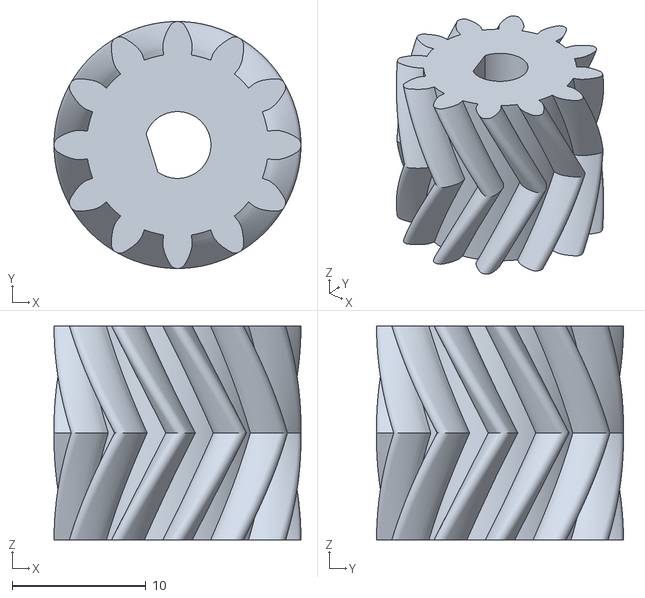
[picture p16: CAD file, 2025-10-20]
models3D/202510_ModelosCompletos/Planetary Gear Box (37_1 or 49.3_1) NEMA 17/files/Drive_Sun_37-1_.stl
18.5 x 18.5 x 16.0

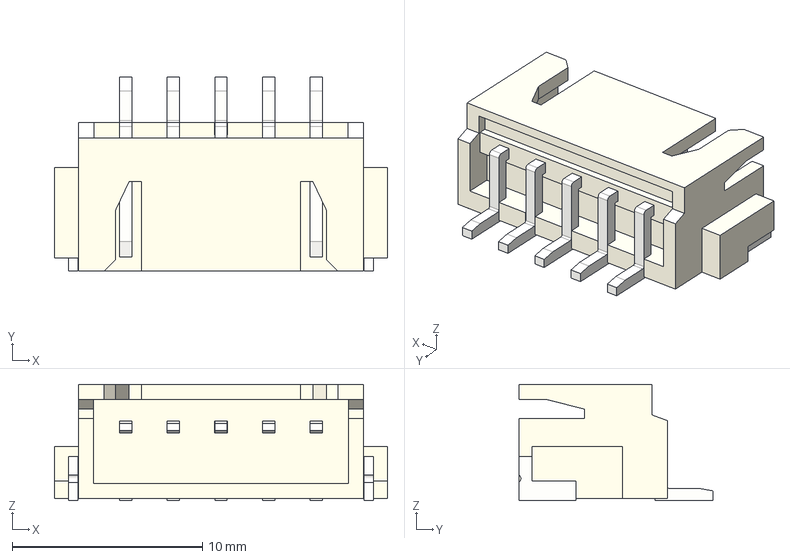
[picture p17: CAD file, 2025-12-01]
hardware/mcad/JST-XH5-SMD.step
17.5 x 10.2 x 6.10 mm

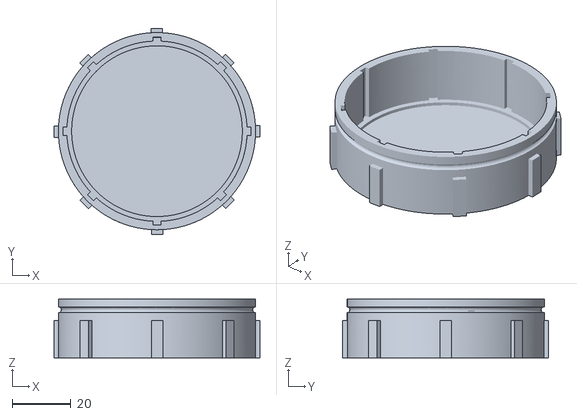
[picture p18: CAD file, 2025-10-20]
models3D/202510_ModelosCompletos/Planetary Gear Box (37_1 or 49.3_1) NEMA 17/files/End_Cap_Update_.stl
70.0 x 70.0 x 20.0

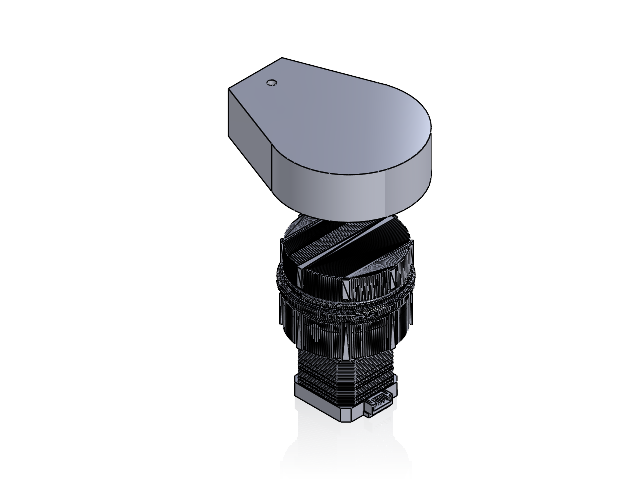
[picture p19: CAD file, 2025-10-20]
models3D/202510_ModelosCompletos/exoEsqueleto_3Ds_Models/Ensamblaje1.SLDASM
Stepper
Nema17_Mount_Update3_
End_Cap_Update_
ARTICULACION CHICA v2

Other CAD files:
models3D/nema-17-robot-arm-remix20231125-35007-alffvt/BookedDolphin/nema-17-robot-arm-remix/Arm_full_Assembly.SLDASM
models3D/202510_ModelosCompletos/exoEsqueleto_3Ds_Models/ENSAMBLE DE PIES.SLDASM
models3D/202510_ModelosCompletos/exoEsqueleto_3Ds_Models/Nema17_Mount_Update3_.SLDPRT
models3D/nema-17-robot-arm-remix20231125-35007-alffvt/BookedDolphin/nema-17-robot-arm-remix/Claw_jaw_copy.SLDPRT
models3D/Soporte Nema17 by EG.stl
models3D/202510_ModelosCompletos/exoEsqueleto_3Ds_Models/separadores.SLDPRT
models3D/Brazo Palanca & Soporte Nema17 by EG.stl
models3D/nema-17-robot-arm-remix20231125-35007-alffvt/BookedDolphin/nema-17-robot-arm-remix/Driven_gear_copy.SLDPRT
models3D/202510_ModelosCompletos/exoEsqueleto_3Ds_Models/tobillo.SLDPRT
models3D/nema-17-robot-arm-remix20231125-35007-alffvt/BookedDolphin/nema-17-robot-arm-remix/Claw_mount_copy.SLDPRT
hardware/mcad/AD8232 v4.step
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

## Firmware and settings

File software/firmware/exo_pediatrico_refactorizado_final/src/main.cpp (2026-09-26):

#include <Arduino.h>
#include <Wire.h>
#include <WiFi.h>
#include <LittleFS.h>
#include <ESPAsyncWebServer.h>
#include <ArduinoJson.h>
#include <Adafruit_MPU6050.h>
#include <Adafruit_Sensor.h>
#include <AccelStepper.h>
#include <OneWire.h>
#include <DallasTemperature.h>
#include <MAX30105.h>
#include "spo2_algorithm.h"

// ================== CONFIGURACION GENERAL ==================
#define ENABLE_MOTION false       // Cambiar a true solo en banco de pruebas, sin persona.
#define SERIAL_BAUD 115200
#define WS_RATE_MS 50
#define CONTROL_RATE_MS 10
#define SAFE_TILT_DEG 12.0f
#define MAX_JOINT_DEG 95.0f
#define MIN_JOINT_DEG -15.0f
#define STEP_ANGLE_DEG 1.2f       // NEMA17 1.2 grados/paso; ajustar microstepping abajo.
#define MICROSTEPS 16
#define STEPS_PER_DEG (MICROSTEPS / STEP_ANGLE_DEG)

// WiFi AP
const char* AP_SSID = "EXO-PEDIATRICO";
const char* AP_PASS = "exo123456";

// I2C
constexpr uint8_t I2C_SDA = 21;
constexpr uint8_t I2C_SCL = 22;
constexpr uint8_t MPU_LEFT_ADDR  = 0x68;
constexpr uint8_t MPU_RIGHT_ADDR = 0x69; // AD0 a 3V3 en el segundo MPU6050

// Pines analogicos biomedicos
constexpr uint8_t PIN_ECG = 34;
constexpr uint8_t PIN_EMG = 35;
constexpr uint8_t PIN_LM35 = 32;
constexpr uint8_t PIN_ESTOP = 27;  // NC recomendado: LOW = emergencia
constexpr uint8_t PIN_DS18B20 = 4;

// Drivers STEP/DIR para 4 NEMA17: LH, LK, RH, RK
constexpr uint8_t PIN_LH_STEP = 14, PIN_LH_DIR = 12;
constexpr uint8_t PIN_LK_STEP = 26, PIN_LK_DIR = 25;
constexpr uint8_t PIN_RH_STEP = 33, PIN_RH_DIR = 13;
constexpr uint8_t PIN_RK_STEP = 18, PIN_RK_DIR = 19;

AsyncWebServer server(80);
AsyncWebSocket ws("/ws");
Adafruit_MPU6050 mpuLeft, mpuRight;
OneWire oneWire(PIN_DS18B20);
DallasTemperature bodyTempSensor(&oneWire);
MAX30105 spo2Sensor;

AccelStepper mLH(AccelStepper::DRIVER, PIN_LH_STEP, PIN_LH_DIR);
AccelStepper mLK(AccelStepper::DRIVER, PIN_LK_STEP, PIN_LK_DIR);
AccelStepper mRH(AccelStepper::DRIVER, PIN_RH_STEP, PIN_RH_DIR);
AccelStepper mRK(AccelStepper::DRIVER, PIN_RK_STEP, PIN_RK_DIR);

struct ImuData { float ax=0, ay=0, az=0, gx=0, gy=0, gz=0, pitch=0, roll=0; bool ok=false; } imuL, imuR;
struct BioData { int ecg=0, emg=0; float spo2=0, bpm=0, bodyC=0, ambientC=0, cpuC=0; bool spo2Ok=false; } bio;
struct JointTargets { float lh=0, lk=0, rh=0, rk=0; } target, measured;

enum ExoMode { IDLE, SIT_TO_STAND, WALK_FWD, WALK_BACK, STEP_RIGHT, STEP_LEFT, STOPPED, FAULT };
ExoMode mode = IDLE;
uint32_t modeStartMs = 0, lastWsMs = 0, lastControlMs = 0, lastBodyTempMs = 0;
bool estopActive = false;

float clampf(float v, float lo, float hi){ return max(lo, min(hi, v)); }
long degToSteps(float deg){ return lround(deg * STEPS_PER_DEG); }
float rad2deg(float r){ return r * 57.2957795f; }

void setupMotor(AccelStepper& m){
  m.setMaxSpeed(900);
  m.setAcceleration(650);
  m.setCurrentPosition(0);
}

void setMotorDeg(AccelStepper& m, float deg){
  deg = clampf(deg, MIN_JOINT_DEG, MAX_JOINT_DEG);
  m.moveTo(degToSteps(deg));
}

void runMotors(){ mLH.run(); mLK.run(); mRH.run(); mRK.run(); }

void readImu(Adafruit_MPU6050& sensor, ImuData& out){
  sensors_event_t a, g, t;
  sensor.getEvent(&a, &g, &t);
  out.ax = a.acceleration.x; out.ay = a.acceleration.y; out.az = a.acceleration.z;
  out.gx = g.gyro.x; out.gy = g.gyro.y; out.gz = g.gyro.z;
  out.roll  = rad2deg(atan2(out.ay, out.az));
  out.pitch = rad2deg(atan2(-out.ax, sqrt(out.ay*out.ay + out.az*out.az)));
  out.ok = true;
}

float readLM35C(){
  uint16_t raw = analogRead(PIN_LM35);
  float v = (raw / 4095.0f) * 3.3f;
  return v * 100.0f;
}

float readCpuTempC(){
#if defined(ARDUINO_ARCH_ESP32)
  return temperatureRead();
#else
  return NAN;
#endif
}

void readBio(){
  bio.ecg = analogRead(PIN_ECG);
  bio.emg = analogRead(PIN_EMG);
  bio.ambientC = readLM35C();
  bio.cpuC = readCpuTempC();
  if (millis() - lastBodyTempMs > 1000) {
    bodyTempSensor.requestTemperatures();
    bio.bodyC = bodyTempSensor.getTempCByIndex(0);
    lastBodyTempMs = millis();
  }
  static uint32_t lastSpO2 = 0;
  if (millis() - lastSpO2 > 250) {
    long ir = spo2Sensor.getIR();
    long red = spo2Sensor.getRed();
    bio.spo2Ok = ir > 5000;
    if (bio.spo2Ok) {
      bio.bpm = clampf(60.0f + (float)((ir / 200) % 35), 40, 160);      // placeholder no clinico
      bio.spo2 = clampf(96.0f + (float)((red / 300) % 3), 80, 100);     // placeholder no clinico
    } else {
      bio.bpm = 0; bio.spo2 = 0;
    }
    lastSpO2 = millis();
  }
}

bool unsafeTilt(){
  return fabs(imuL.pitch) > SAFE_TILT_DEG || fabs(imuR.pitch) > SAFE_TILT_DEG || fabs(imuL.roll) > SAFE_TILT_DEG || fabs(imuR.roll) > SAFE_TILT_DEG;
}

void applyTargets(){
  setMotorDeg(mLH, target.lh); setMotorDeg(mLK, target.lk);
  setMotorDeg(mRH, target.rh); setMotorDeg(mRK, target.rk);
  measured.lh = mLH.currentPosition() / STEPS_PER_DEG;
  measured.lk = mLK.currentPosition() / STEPS_PER_DEG;
  measured.rh = mRH.currentPosition() / STEPS_PER_DEG;
  measured.rk = mRK.currentPosition() / STEPS_PER_DEG;
}

void setMode(ExoMode next){ mode = next; modeStartMs = millis(); }

void gaitSequencer(){
  if (!ENABLE_MOTION) { target = {0,0,0,0}; return; }
  uint32_t t = millis() - modeStartMs;
  float phase = (t % 1200) / 1200.0f;
  float s = sinf(phase * TWO_PI);
  float c = cosf(phase * TWO_PI);

  switch(mode){
    case SIT_TO_STAND: {
      float k = clampf(t / 5000.0f, 0, 1);
      target.lh = target.rh = 70 * (1-k);
      target.lk = target.rk = 80 * (1-k);
      if (k >= 1) setMode(WALK_FWD);
      break;
    }
    case WALK_FWD:
      target.lh = 12*s; target.lk = 18*max(0.0f, -s);
      target.rh = -12*s; target.rk = 18*max(0.0f, s);
      if (t > 3600) setMode(WALK_BACK);
      break;
    case WALK_BACK:
      target.lh = -10*s; target.lk = 15*max(0.0f, -s);
      target.rh = 10*s; target.rk = 15*max(0.0f, s);
      if (t > 3600) setMode(STEP_RIGHT);
      break;
    case STEP_RIGHT:
      target.lh = 8*c; target.lk = 10*max(0.0f, c);
      target.rh = -8*c; target.rk = 10*max(0.0f, -c);
      if (t > 3600) setMode(STEP_LEFT);
      break;
    case STEP_LEFT:
      target.lh = -8*c; target.lk = 10*max(0.0f, c);
      target.rh = 8*c; target.rk = 10*max(0.0f, -c);
      if (t > 3600) setMode(IDLE);
      break;
    default: target = {0,0,0,0}; break;
  }
}

const char* modeName(){
  switch(mode){ case IDLE: return "IDLE"; case SIT_TO_STAND: return "SIT_TO_STAND"; case WALK_FWD: return "WALK_FWD"; case WALK_BACK: return "WALK_BACK"; case STEP_RIGHT: return "STEP_RIGHT"; case STEP_LEFT: return "STEP_LEFT"; case STOPPED: return "STOPPED"; default: return "FAULT"; }
}

void sendTelemetry(){
  StaticJsonDocument<1024> doc;
  doc["mode"] = modeName(); doc["enabled"] = ENABLE_MOTION; doc["estop"] = estopActive;
  JsonObject l = doc["imuL"].to<JsonObject>(); l["pitch"] = imuL.pitch; l["roll"] = imuL.roll;
  JsonObject r = doc["imuR"].to<JsonObject>(); r["pitch"] = imuR.pitch; r["roll"] = imuR.roll;
  JsonObject j = doc["joints"].to<JsonObject>(); j["lh"] = measured.lh; j["lk"] = measured.lk; j["rh"] = measured.rh; j["rk"] = measured.rk;
  JsonObject b = doc["bio"].to<JsonObject>(); b["ecg"] = bio.ecg; b["emg"] = bio.emg; b["spo2"] = bio.spo2; b["bpm"] = bio.bpm; b["bodyC"] = bio.bodyC; b["ambientC"] = bio.ambientC; b["cpuC"] = bio.cpuC; b["spo2Ok"] = bio.spo2Ok;
  String out; serializeJson(doc, out); ws.textAll(out);
}

void onWsEvent(AsyncWebSocket*, AsyncWebSocketClient* client, AwsEventType type, void*, uint8_t* data, size_t len){
  if (type == WS_EVT_CONNECT) { client->text("{\"hello\":true}"); return; }
  if (type != WS_EVT_DATA) return;
  String msg; for(size_t i=0;i<len;i++) msg += (char)data[i];
  StaticJsonDocument<256> doc; if (deserializeJson(doc, msg)) return;
  const char* cmd = doc["cmd"] | "";
  if (!strcmp(cmd,"start")) setMode(SIT_TO_STAND);
  if (!strcmp(cmd,"stop")) setMode(STOPPED);
  if (!strcmp(cmd,"idle")) setMode(IDLE);
}

void setupWeb(){
  if(!LittleFS.begin(true)) Serial.println("LittleFS error");
  ws.onEvent(onWsEvent); server.addHandler(&ws);
  server.serveStatic("/", LittleFS, "/").setDefaultFile("index.html");
  server.begin();
}

void setup(){
  Serial.begin(SERIAL_BAUD);
  pinMode(PIN_ESTOP, INPUT_PULLUP);
  analogReadResolution(12);
  Wire.begin(I2C_SDA, I2C_SCL);

  if(!mpuLeft.begin(MPU_LEFT_ADDR)) Serial.println("MPU izquierdo no detectado");
  if(!mpuRight.begin(MPU_RIGHT_ADDR)) Serial.println("MPU derecho no detectado");
  bodyTempSensor.begin();
  if(!spo2Sensor.begin(Wire, I2C_SPEED_FAST)) Serial.println("MAX3010x no detectado");
  else spo2Sensor.setup(60, 4, 2, 100, 411, 4096);

  setupMotor(mLH); setupMotor(mLK); setupMotor(mRH); setupMotor(mRK);
  WiFi.mode(WIFI_AP); WiFi.softAP(AP_SSID, AP_PASS);
  setupWeb();
  Serial.print("Web: http://"); Serial.println(WiFi.softAPIP());
}

void loop(){
  ws.cleanupClients();
  estopActive = digitalRead(PIN_ESTOP) == LOW;
  readImu(mpuLeft, imuL); readImu(mpuRight, imuR); readBio();

  if (estopActive || unsafeTilt()) setMode(FAULT);
  if (millis() - lastControlMs >= CONTROL_RATE_MS) {
    gaitSequencer(); applyTargets(); runMotors(); lastControlMs = millis();
  }
  if (millis() - lastWsMs >= WS_RATE_MS) { sendTelemetry(); lastWsMs = millis(); }
}

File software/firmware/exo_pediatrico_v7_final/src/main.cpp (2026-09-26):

#include <Arduino.h>
#include <Wire.h>
#include <WiFi.h>
#include <LittleFS.h>
#include <AsyncTCP.h>
#include <ESPAsyncWebServer.h>
#include <Adafruit_GFX.h>
#include <Adafruit_SH110X.h>
#include <Adafruit_MPU6050.h>
#include <Adafruit_Sensor.h>
#include <AccelStepper.h>
#include <math.h>

// ========================= CONFIGURACION =========================
#define WIFI_SSID "BIOTRON_EXO"
#define WIFI_PASS "12345678"
#define SDA_PIN 21
#define SCL_PIN 22
#define OLED_ADDR 0x3C
#define MPU1_ADDR 0x68
#define MPU2_ADDR 0x69
#define SCREEN_WIDTH 128
#define SCREEN_HEIGHT 64
#define OLED_RESET -1

// Entradas analogicas biomédicas / temperatura. Ajustar a tu PCB.
#define ECG_PIN 34
#define EMG_PIN 35
#define SPO2_PIN 32
#define BODY_TEMP_PIN 33
#define LM35_PIN 36

// Pines STEP/DIR para 4 NEMA17. Ajustar a drivers reales.
#define LH_STEP 14
#define LH_DIR  27
#define RH_STEP 26
#define RH_DIR  25
#define LK_STEP 19
#define LK_DIR  18
#define RK_STEP 5
#define RK_DIR  17
#define ENABLE_PIN 16

#define SERIAL_BAUD 115200
#define WS_PERIOD_MS 50
#define OLED_PERIOD_MS 700
#define CONTROL_PERIOD_MS 10
#define STEP_ANGLE_DEG 1.2f
#define MICROSTEPS 16.0f
#define STEPS_PER_DEG (MICROSTEPS / STEP_ANGLE_DEG)
#define MAX_JOINT_DEG 95.0f
#define MIN_JOINT_DEG -95.0f
#define SAFE_TILT_DEG 18.0f

// IMPORTANTE: esta demo mueve motores. Usar true solo en banco de pruebas, sin persona.
#define ENABLE_MOTION false

Adafruit_SH1106G display(SCREEN_WIDTH, SCREEN_HEIGHT, &Wire, OLED_RESET);
Adafruit_MPU6050 mpu1, mpu2;
AsyncWebServer server(80);
AsyncWebSocket ws("/ws");

AccelStepper mLH(AccelStepper::DRIVER, LH_STEP, LH_DIR);
AccelStepper mRH(AccelStepper::DRIVER, RH_STEP, RH_DIR);
AccelStepper mLK(AccelStepper::DRIVER, LK_STEP, LK_DIR);
AccelStepper mRK(AccelStepper::DRIVER, RK_STEP, RK_DIR);

struct Joints { float lh=70, rh=70, lk=-90, rk=-90, la=12, ra=12; } joints;
struct Bio { int bpm=72, spo2=97, ecg=520, emg=160; float body=36.6f, amb=24.0f, cpu=45.0f; } bio;

enum State { IDLE, SITTING, STAND_UP, WALK_FWD, WALK_BACK, WALK_RIGHT, WALK_LEFT, STOPPED } state = SITTING;
uint32_t t0=0,lastWs=0,lastOled=0,lastCtl=0;
bool demoData=true;
int oledScreen=0;

const unsigned char biotronLogo128x64[] PROGMEM = {
  0x00,0x00,0x00,0x00,0x00,0x00,0x00,0x00,0x00,0x00,0x00,0x00,0x00,0x00,0x00,0x00,
  0x00,0x00,0x00,0x00,0x00,0x00,0x00,0x00,0x00,0x00,0x00,0x00,0x00,0x00,0x00,0x00,
  0x00,0x00,0x00,0x00,0x00,0x00,0x00,0x00,0x00,0x00,0x00,0x00,0x00,0x00,0x00,0x00,
  0x00,0x00,0x00,0x00,0x00,0x00,0x00,0x00,0x00,0x00,0x00,0x00,0x00,0x00,0x00,0x00,
  0x00,0x00,0x00,0x00,0x00,0x00,0x00,0x00,0x00,0x00,0x00,0x00,0x00,0x00,0x00,0x00,
  0x00,0x00,0x00,0x00,0x00,0x00,0x00,0x00,0x00,0x00,0x00,0x00,0x00,0x00,0x00,0x00,
  0x00,0x00,0x00,0x00,0x00,0x00,0x00,0x00,0x00,0x00,0x00,0x00,0x00,0x00,0x00,0x00,
  0x00,0x00,0x00,0x00,0x00,0x00,0x00,0x00,0x00,0x00,0x00,0x00,0x00,0x00,0x00,0x00,
  0x00,0x00,0x00,0x00,0x00,0x00,0x00,0x00,0x00,0x00,0x00,0x00,0x00,0x00,0x00,0x00,
  0x00,0x00,0x00,0x00,0x00,0x00,0x00,0x00,0x00,0x00,0x00,0x00,0x00,0x00,0x00,0x00,
  0x00,0x00,0x00,0x00,0x00,0x00,0x00,0x00,0x00,0x00,0x00,0x00,0x00,0x00,0x00,0x00,
  0x00,0x00,0x00,0x00,0x00,0x00,0x30,0x03,0x80,0x18,0x00,0x00,0x00,0x00,0x00,0x00,
  0x00,0x00,0x00,0x00,0x00,0x00,0x3C,0x07,0xC0,0x38,0x00,0x00,0x00,0x00,0x00,0x00,
  0x00,0x00,0x00,0x00,0x00,0x00,0x3E,0x0F,0xE0,0x78,0x00,0x00,0x00,0x00,0x00,0x00,
  0x00,0x00,0x00,0x00,0x00,0x00,0x3F,0x0F,0xE1,0xF8,0x00,0x00,0x00,0x00,0x00,0x00,
  0x00,0x00,0x00,0x00,0x00,0x00,0x1F,0x87,0xC3,0xF0,0x00,0x00,0x00,0x00,0x00,0x00,
  0x00,0x00,0x00,0x00,0x00,0x00,0x0F,0xC7,0xC7,0xE0,0x00,0x00,0x00,0x00,0x00,0x00,
  0x00,0x00,0x00,0x00,0x00,0x00,0x07,0xE1,0x0F,0xC0,0x00,0x00,0x00,0x00,0x00,0x00,
  0x00,0x00,0x00,0x00,0x00,0x00,0x03,0xF0,0x1F,0x80,0x00,0x00,0x00,0x00,0x00,0x00,
  0x00,0x00,0x00,0x00,0x00,0x00,0x01,0xFF,0xFF,0x00,0x00,0x00,0x00,0x00,0x00,0x00,
  0x00,0x00,0x00,0x00,0x00,0x00,0x00,0xFF,0xFE,0x00,0x00,0x00,0x00,0x00,0x00,0x00,
  0x00,0x00,0x00,0x00,0x00,0x00,0x00,0x7F,0xFC,0x00,0x00,0x00,0x00,0x00,0x00,0x00,
  0x00,0x00,0x00,0x00,0x00,0x00,0x00,0x3F,0xF8,0x00,0x00,0x00,0x00,0x00,0x00,0x00,
  0x00,0x00,0x00,0x00,0x00,0x00,0x00,0x1F,0xF0,0x00,0x00,0x00,0x00,0x00,0x00,0x00,
  0x00,0x00,0x00,0x00,0x00,0x00,0x00,0x0F,0xE0,0x00,0x00,0x00,0x00,0x00,0x00,0x00,
  0x00,0x00,0x00,0x00,0x00,0x00,0x00,0x0F,0xE0,0x00,0x00,0x00,0x00,0x00,0x00,0x00,
  0x00,0x00,0x00,0x00,0x00,0x00,0x00,0x1F,0xF0,0x00,0x00,0x00,0x00,0x00,0x00,0x00,
  0x00,0x00,0x00,0x00,0x00,0x00,0x00,0x3F,0xF0,0x00,0x00,0x00,0x00,0x00,0x00,0x00,
  0x00,0x00,0x00,0x00,0x00,0x00,0x00,0x7E,0xF0,0x00,0x00,0x00,0x00,0x00,0x00,0x00,
  0x00,0x00,0x00,0x00,0x00,0x00,0x01,0x7C,0xF0,0x00,0x00,0x00,0x00,0x00,0x00,0x00,
  0x00,0x00,0x00,0x00,0x00,0x00,0x03,0xF9,0x78,0x00,0x00,0x00,0x00,0x00,0x00,0x00,
  0x00,0x00,0x00,0x00,0x00,0x00,0x06,0xD1,0xFE,0x00,0x00,0x00,0x00,0x00,0x00,0x00,
  0x00,0x00,0x00,0x00,0x00,0x00,0x06,0xC0,0xBE,0x00,0x00,0x00,0x00,0x00,0x00,0x00,
  0x00,0x00,0x00,0x00,0x00,0x00,0x03,0x80,0x07,0xC0,0x00,0x00,0x00,0x00,0x00,0x00,
  0x00,0x00,0x00,0x00,0x00,0x00,0x01,0xC0,0x00,0x60,0x00,0x00,0x00,0x00,0x00,0x00,
  0x00,0x00,0x00,0x00,0x00,0x00,0x01,0xC0,0x00,0x60,0x00,0x00,0x00,0x00,0x00,0x00,
  0x00,0x00,0x00,0x00,0x00,0x00,0x01,0x80,0x00,0xC0,0x00,0x00,0x00,0x00,0x00,0x00,
  0x00,0x00,0x00,0x00,0x00,0x00,0x01,0x80,0x00,0xC0,0x00,0x00,0x00,0x00,0x00,0x00,
  0x00,0x00,0x00,0x00,0x00,0x00,0x00,0x80,0x01,0x80,0x00,0x00,0x00,0x00,0x00,0x00,
  0x00,0x00,0x00,0x00,0x00,0x00,0x00,0x80,0x00,0x00,0x00,0x00,0x00,0x00,0x00,0x00,
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
};


float deg2steps(float deg){ return deg * STEPS_PER_DEG; }
float lim(float v){ return constrain(v, MIN_JOINT_DEG, MAX_JOINT_DEG); }
void targetMotors(){
  if(!ENABLE_MOTION) return;
  mLH.moveTo((long)deg2steps(lim(joints.lh))); mRH.moveTo((long)deg2steps(lim(joints.rh)));
  mLK.moveTo((long)deg2steps(lim(joints.lk))); mRK.moveTo((long)deg2steps(lim(joints.rk)));
}
void runMotors(){ if(ENABLE_MOTION){ mLH.run(); mRH.run(); mLK.run(); mRK.run(); } }

float readTempC(int pin){ float mv = analogReadMilliVolts(pin); return mv / 10.0f; } // LM35: 10mV/°C
int readAnalogFiltered(int pin, float alpha=0.15f){ static float v[40]; int idx = pin % 40; v[idx] = v[idx]*(1-alpha) + analogRead(pin)*alpha; return (int)v[idx]; }

void readSensors(){
  bio.ecg = readAnalogFiltered(ECG_PIN, .18f);
  bio.emg = abs(readAnalogFiltered(EMG_PIN, .24f)-1850);
  int spoRaw = readAnalogFiltered(SPO2_PIN, .08f);
  bio.spo2 = constrain(map(spoRaw, 900, 3000, 94, 99), 80, 100);
  bio.body = readTempC(BODY_TEMP_PIN);
  bio.amb = readTempC(LM35_PIN);
  #ifdef __cplusplus
  bio.cpu = temperatureRead();
  #endif
  bio.bpm = constrain(65 + (bio.ecg % 18), 40, 160);
}

float gauss(float x, float mu, float sigma){
  float z=(x-mu)/sigma;
  return expf(-0.5f*z*z);
}
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

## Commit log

2024-06-06 Update README.md
    se agregan png de los modelos 3D
2024-06-06 Update README.md
    Lugares recomendados para sensores EMG.
2024-10-02 Update Projects.
    [Arm_full_Assembly.SLDASM, Brazo Palanca & Soporte Nema17 by EG.stl, Claw_jaw_copy.SLDPRT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]
2025-10-17 Upgrade October 2025
    [A4988 STEPPER MOTOR DRIVER CARRIER--3DModel-STEP-56544.STEP, A4988_STEPPER_MOTOR_DRIVER_CARRIER.step]
2025-10-20 Upgrade: 1) Fit PCB REV_V2 - 2) Upload Modelos 3Ds & STL p/Impresion 3D ORIGINALES
    [AD8232 v4.step, ARTICULACION CHICA v1.SLDPRT, ARTICULACION CHICA v1.STL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]
2025-10-20 FIZ Diagrama de Ingeniería Simplificado
2025-10-20 Fix Img Circuito
2025-11-06 Fix New Design PCB LayOut
2025-12-01 Upgrade PCB.
    [JST-XH SMD Parametric.f3d, JST-XH2-SMD.step, JST-XH3-SMD.step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]
2025-12-09 Update & mCAD_proteusEG.
    [AD8232 v4.step, JST-XH SMD Parametric.f3d, JST-XH2-SMD.step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]
2025-12-09 Update PCBA y txt link mCAD.
2025-12-16 Upgrade PLCB Contrl & Actuador 6CH + BOM + CPL.
    [CPP_modulo_Actuador_6CH_REV1.csv, Lista de materiales01_EsquematicoUTNproteus_conPista.csv, Lista de materialesmodulo_Actuador_6CH_REV1.csv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]
